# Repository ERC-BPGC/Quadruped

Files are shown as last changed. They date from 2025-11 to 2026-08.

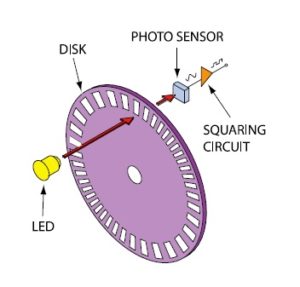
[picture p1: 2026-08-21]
docs/mechanical/assets/encoders/optical.jpg

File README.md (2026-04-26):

# ERC Quadruped

Official repository for the ERC-BPGC quadruped robotics project.

This repo is being organized into a long-term handoff and documentation hub for the robot: CAD, electronics, software, controls, simulation, assembly notes, experiments, and future work.

**Docs site:** https://erc-bpgc.github.io/Quadruped/

## Documentation

The project documentation is built with Docusaurus and hosted with GitHub Pages:

```text
https://erc-bpgc.github.io/Quadruped/
```

Local docs workflow:

```bash
nvm use
npm install
npm run start
```

Modern Docusaurus requires Node.js 20 or newer.

## Repository areas

- `docs/` - documentation pages
- `src/` - Docusaurus homepage and styling
- `static/` - images and static website assets
- `Genesis/` - simulation/source material currently present in the repo

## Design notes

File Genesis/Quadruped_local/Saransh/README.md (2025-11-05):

# Quadruped Control System

A comprehensive control system for a quadruped robot with ODrive motor controllers, featuring a GUI interface, live plotting, parameter tuning, and 3D visualization.

## Features

- **Configuration File System**: Easy-to-modify YAML configuration for all ODrive and system parameters
- **3D Visualization**: Interactive skeletal model with joint angle and foot position controls
- **Live Plotting**: Real-time plotting of motor currents, positions, velocities, and other parameters
- **Parameter Tuning**: Live modification of PID constants, current limits, and other ODrive parameters
- **Simulation Mode**: Test all functionality without hardware connection
- **Calibration System**: Simultaneous or sequential motor calibration
- **Emergency Controls**: Emergency stop and safety features

## File Structure

```
Quadruped/Saransh/
├── config.yaml                 # Main configuration file
├── quadruped_gui.py            # Main GUI application
├── quadruped_enhanced.py       # Enhanced quadruped control with config support
├── plotting_utils.py           # Plotting and data collection utilities
├── Quadruped_final_legs.py     # Original quadruped control (backward compatibility)
├── Quadruped_leg_test_algo.py  # Inverse kinematics algorithms
├── requirements.txt            # Python package requirements
└── README.md                   # This file
```

## Installation

1. **Install Python dependencies:**
   ```bash
   pip install -r requirements.txt
   ```

2. **Install ODrive (if using real hardware):**
   ```bash
   pip install odrive
   ```
   Follow the [ODrive setup guide](https://docs.odriverobotics.com/) for hardware setup.

3. **Verify installation:**
   ```bash
   python quadruped_gui.py
   ```

## Configuration

### Main Configuration File (config.yaml)

The `config.yaml` file contains all system parameters:

- **System Settings**: Simulation mode, calibration preferences
- **ODrive Mapping**: Serial number to leg assignment
- **Motor Parameters**: PID gains, current limits, encoder settings
- **Leg Geometry**: Link lengths and physical parameters
- **GUI Settings**: Window size, update rates, visualization options

### Key Configuration Sections

#### Motor Configuration
```yaml
motor_config:
  hip:
    pos_gain: 50.0
    vel_gain: 0.05
    current_lim: 20.0
    # ... other parameters
  knee:
    pos_gain: 20.0
    vel_gain: 0.02
    current_lim: 60.0
    # ... other parameters
```

#### ODrive Serial Mapping
```yaml
odrive_mapping:
  "3670314C3333": "front_left"
  "366B315F3333": "front_right"
  "367031553333": "back_left"
  "3669315C3333": "back_right"
```

## Usage

### GUI Application

1. **Start the GUI:**
   ```bash
   python quadruped_gui.py
   ```

2. **Simulation Mode:**
   - Set `simulation_mode: true` in config.yaml
   - Or toggle via the Connection menu
   - Test all features without hardware

3. **Hardware Mode:**
   - Set `simulation_mode: false` in config.yaml
   - Connect ODrives via "Connection" → "Connect to ODrives"

### GUI Tabs

#### 1. Visualization & Pose Control
- **3D Skeleton**: Interactive 3D model of the quadruped
- **Joint Controls**: Sliders for hip and knee angles
- **Foot Position**: X/Y position controls with inverse kinematics
- **Send to Dog**: Apply current pose to physical robot
- **Emergency Stop**: Immediate motor shutdown

#### 2. Motor Control
- Direct motor control interfaces
- Individual leg selection
- Position and velocity commands

#### 3. Live Plotting
- **Real-time Data**: Plot motor currents, positions, velocities
- **Parameter Selection**: Dropdown to choose what to plot
- **Multi-motor Display**: All 8 motors plotted simultaneously
- **Data Export**: Save plot data for analysis

#### 4. Parameter Tuning
- **Live PID Tuning**: Adjust gains in real-time
- **Current Limits**: Modify motor current limits
- **Velocity Limits**: Set speed constraints
- **Presets**: Save and load parameter configurations

#### 5. Calibration & Setup
- **Motor Calibration**: Simultaneous or sequential calibration
- **Home Position**: Set reference positions
- **Motor Testing**: Verify motor functionality

### Command Line Interface

1. **Original Interface:**
   ```bash
   python Quadruped_final_legs.py
   ```

2. **Enhanced Interface with Config:**
   ```bash
   python quadruped_enhanced.py
   ```

## Hardware Setup

### ODrive Configuration

1. **Serial Numbers**: Update `odrive_mapping` in config.yaml with your ODrive serial numbers
2. **Motor Parameters**: Adjust motor configurations for your specific motors
3. **Encoder Settings**: Configure for your encoder types (incremental for hips, hall for knees)

### Physical Connections

- **Front Left**: ODrive 1 (axis0: hip, axis1: knee)
- **Front Right**: ODrive 2 (axis0: hip, axis1: knee)
- **Back Left**: ODrive 3 (axis0: hip, axis1: knee)
- **Back Right**: ODrive 4 (axis0: hip, axis1: knee)

## Safety Features

### Emergency Stop
- **GUI Button**: Red emergency stop button in visualization tab
- **Keyboard**: Ctrl+C to interrupt operations
- **Automatic**: Safety limits in configuration

### Parameter Limits
```yaml
safety:
  max_current: 80.0
  max_velocity: 25.0
  max_position_error: 5.0
  emergency_stop_enabled: true
```

## Troubleshooting

### Common Issues

1. **ODrive Connection Failed**
   - Check USB connections
   - Verify serial numbers in config.yaml
   - Use `odrivetool` to test individual connections

2. **Calibration Errors**
   - Ensure motors can rotate freely
   - Check encoder wiring
   - Verify motor parameters

3. **GUI Not Starting**
   - Install missing dependencies: `pip install -r requirements.txt`
   - Check Python version (3.7+ required)

4. **Plotting Issues**
   - Reduce update rate in config.yaml
   - Check simulation_mode setting
   - Verify data collection parameters

### Debug Mode

Enable verbose output by modifying the configuration:
```yaml
system:
  debug_mode: true
  log_level: "DEBUG"
```

## Development

### Adding New Features

1. **New Parameters**: Add to `motor_config` in config.yaml
2. **GUI Widgets**: Extend the respective tab classes
3. **Plotting**: Add new parameters to `plotting_utils.py`

### Testing

1. **Simulation Mode**: Test without hardware
2. **Unit Tests**: Run individual components
3. **Hardware Testing**: Use with actual ODrives

## Support

- **Documentation**: See inline code comments
- **Configuration**: All parameters documented in config.yaml
- **Issues**: Check troubleshooting section above

## Version History

- **v1.0**: Initial GUI implementation with all major features
- **v0.9**: Enhanced quadruped control with config file support
- **v0.8**: Original command-line interface

## License

This project is part of the ERC Quadruped development effort.

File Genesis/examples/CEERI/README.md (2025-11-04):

# Indoor Drone Exploration with LiDAR

This directory contains a custom implementation of an autonomous indoor drone exploration system using reinforcement learning (PPO) with LiDAR-based navigation.

## 📋 Overview

This project implements a drone navigation system for indoor maze exploration based on the research paper:
**"Exploring Unknown Indoors with Drone using Multi-Critic DDPG Architecture"** (Kishore et al.)

The implementation uses:
- **2D LiDAR sensor** for obstacle detection (180° horizontal coverage)
- **Velocity-based control** (x_vel, y_vel, yaw_rate commands)
- **Hybrid reward structure** from the paper (variable pitch, obstacle avoidance, center alignment)
- **PPO algorithm** for training (single-critic, extensible to multi-critic later)
- **MJCF maze environment** with corridors, turns, and obstacles

## 🚀 Quick Start

### 0. Installation

Install required dependencies:

```bash
pip install --upgrade pip
pip install tensorboard rsl-rl-lib==2.2.4 pynput
```

### 1. Test Environment with Teleoperation

Before training, test the environment and visualize LiDAR sensor:

```bash
python exploration_teleop.py
```

**Keyboard Controls:**
- `↑/↓` : Forward/Backward
- `←/→` : Left/Right (lateral movement)
- `A/D` : Rotate Left/Right (yaw)
- `Space` : Stop (zero velocity)
- `R` : Reset drone
- `ESC` : Quit

The LiDAR rays will be visualized:
- **Green rays**: No obstacle detected
- **Red rays**: Obstacle hit

### 2. Train the Policy

Train the exploration policy using PPO:

```bash
# Basic training (4096 parallel environments)
python exploration_train.py -e drone-exploration -B 4096 --max_iterations 5001

# Training with visualization (slower but useful for debugging)
python exploration_train.py -e drone-exploration -B 4096 --max_iterations 5001 -v

# Quick test with fewer environments
python exploration_train.py -e test-exploration -B 256 --max_iterations 501
```

Monitor training progress with TensorBoard:
```bash
tensorboard --logdir logs/
```

### 3. Evaluate the Trained Policy

Evaluate the trained policy:

```bash
# Basic evaluation
python exploration_eval.py -e drone-exploration --ckpt 5000

# Evaluation with video recording
python exploration_eval.py -e drone-exploration --ckpt 5000 --record

# Evaluate multiple episodes
python exploration_eval.py -e drone-exploration --ckpt 5000 --num_episodes 20
```

## 📁 File Structure

```
CEERI/
├── exploration_env.py          # Main environment with LiDAR sensor
├── exploration_train.py        # Training script (PPO)
├── exploration_eval.py         # Evaluation script
├── exploration_teleop.py       # Manual control for testing
├── README.md                   # This file
└── logs/                       # Training logs and checkpoints
    └── drone-exploration/
        ├── model_*.pt          # Saved model checkpoints
        ├── cfgs.pkl            # Configuration file
        └── events.*            # TensorBoard logs
```

## 🎯 Environment Details

### Observation Space (15D)
- **LiDAR readings (3D)**: [F, R, L]
  - F: Minimum distance forward ([-10°, +10°])
  - R: Minimum distance right ([+10°, +90°])
  - L: Minimum distance left ([-90°, -10°])
- **Linear velocity (3D)**: [vx, vy, vz] in drone frame
- **Euler angles (3D)**: [roll, pitch, yaw]
- **Angular velocity (3D)**: [wx, wy, wz] in drone frame
- **Last actions (3D)**: Previous [x_vel, y_vel, yaw_rate] commands

### Action Space (3D)
- **x_vel**: Forward/backward velocity [-1.5, 1.5] m/s
- **y_vel**: Left/right velocity [-1.5, 1.5] m/s
- **yaw_rate**: Rotation rate [-π/2, π/2] rad/s

Actions are converted to rotor RPMs using a simple proportional controller.

### Reward Structure

Based on the research paper with 4 components:

1. **Variable Pitch** (forward movement encouragement)
   - Rewards faster movement when path is clear
   - Penalizes getting too close to obstacles

2. **Obstacle Avoidance** (repulsive potential)
   - Uses artificial potential hills around obstacles
   - Rewards decreasing repulsion equilibrium

3. **Center Alignment** (attractive potential)
   - Keeps drone centered in corridors
   - Minimizes difference between left/right distances

4. **Exploration** (placeholder)
   - Currently set to zero
   - Reserved for entropy-based exploration reward

Additional rewards:
- Collision penalty
- Smoothness penalty (action jerkiness)
- Angular velocity penalty

### Environment Configuration

Key parameters (see `exploration_env.py` and `exploration_train.py`):

```python
env_cfg = {
    "num_actions": 3,
    "episode_length_s": 60.0,
    "collision_threshold": 0.3,  # meters
    "lidar_n_rays": 128,
    "lidar_max_range": 6.0,  # meters
    "max_x_vel": 1.5,  # m/s
    "max_y_vel": 1.5,  # m/s
    "max_yaw_rate": 1.57,  # rad/s
}
```

## 🏗️ Maze Environment

The maze is defined in `/home/ritwik/NUS/Genesis/meshes/maze_simple.xml` (MJCF format).

Current maze features:
- 10m × 10m arena
- Corridors with varying widths
- Internal walls creating T-junctions
- Cylindrical obstacles/pillars

You can modify the maze by editing the XML file to add:
- More complex corridors
- Different obstacle shapes
- Dead ends and loops
- Multiple floors (for future 3D navigation)

## 🔧 Technical Details

### LiDAR Sensor
- **Type**: 2D (single horizontal plane)
- **FOV**: 180° horizontal ([-90°, +90°])
- **Resolution**: 128 rays (configurable)
- **Range**: 0.1m - 6.0m
- **Update rate**: 100 Hz (same as simulation)

### Velocity Controller
Simple proportional controller converts velocity commands to RPM:
- `kp_vel = 3000.0` for translational velocities
- `kp_yaw = 5000.0` for yaw rate
- Hover RPM: 14468
- RPM range: [5000, 25000]

### Drone Model
- Crazyflie 2.X (`urdf/drones/cf2x.urdf`)
- Quadcopter X-configuration
- Mass: ~0.027 kg
- 4 rotors with differential control

## 📊 Training Tips

1. **Start with fewer environments** (256-512) to verify setup
2. **Monitor TensorBoard** for reward trends and policy metrics
3. **Adjust reward scales** if one component dominates
4. **Use visualization** (`-v` flag) sparingly during training (slows down)
5. **Save checkpoints** regularly (default: every 100 iterations)

Typical training time:
- 256 envs: ~5-10 minutes per 100 iterations (CPU)
- 4096 envs: ~10-20 minutes per 100 iterations (GPU)

## 🎓 Future Extensions

- [ ] Add entropy-based exploration reward
- [ ] Implement multi-critic DDPG architecture
- [ ] Add precision playback buffer
- [ ] 3D LiDAR for vertical obstacle avoidance
- [ ] More complex maze environments
- [ ] Coverage tracking and visualization
- [ ] Real-world transfer (sim-to-real)

## 📚 References

**Paper**: "Exploring Unknown Indoors with Drone using Multi-Critic DDPG Architecture"  
**Authors**: Kaushal Kishore, Chimata Anudeep, Shahid Shaikh, Samarth Singh

Key concepts adapted:
- Hybrid reward structure (repulsive/attractive potentials)
- LiDAR-based state representation
- Multi-dimensional action space

## 🐛 Troubleshooting

**Issue**: Teleop script not responding to keyboard
- **Solution**: Install pynput: `pip install pynput`

**Issue**: MJCF maze not loading
- **Solution**: Check if `meshes/maze_simple.xml` exists. If not, the environment will create simple walls as fallback.

**Issue**: Training very slow
- **Solution**: Disable visualization (`-v` flag), reduce number of environments, or use GPU backend

**Issue**: Drone crashes immediately
- **Solution**: Check controller gains (`kp_vel`, `kp_yaw`), adjust collision threshold, or verify initial position is not inside a wall

## 📝 License

This project is part of the Genesis physics simulation framework research.

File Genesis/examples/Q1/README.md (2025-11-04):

# Q1 Quadruped Walking Task

This folder contains the training and evaluation code for a simple forward walking task for the Q1 custom quadruped robot.

## Robot Specifications

The Q1 quadruped has:
- **8 Degrees of Freedom (DOF)**: 2 per leg (thigh and calf joints only, no hip joint)
- **Joint Configuration**: 
  - Front Left (FL): thigh, calf
  - Front Right (FR): thigh, calf
  - Rear Left (RL): thigh, calf
  - Rear Right (RR): thigh, calf

This is different from robots like the Unitree Go2 which have 12 DOF (3 per leg: hip, thigh, and calf).

## Files

- `q1_env.py`: Environment class for Q1 robot with RL training interface
- `q1_train.py`: Training script using PPO algorithm
- `q1_eval.py`: Evaluation script to visualize trained policy
- `q1_visualize.py`: Standalone script to visualize robot in default pose
- `q1_monitor.py`: Real-time training progress monitor
- `README.md`: This file
- `MODIFICATIONS.md`: Detailed documentation of changes from Go2 code

## MuJoCo XML Files

The robot model is located at: `genesis/assets/xml/q1/q1_mjx_full.xml`

## Configuration

### Environment Configuration
- **Actions**: 8 continuous actions (one per joint)
- **Observations**: 33-dimensional vector containing:
  - Base angular velocity (3)
  - Projected gravity (3)
  - Velocity commands (3)
  - Joint positions relative to default (8)
  - Joint velocities (8)
  - Previous actions (8)

### Default Joint Angles
```python
"FL_thigh_joint": 0.5,
"FL_calf_joint": -0.3,
"FR_thigh_joint": 0.5,
"FR_calf_joint": -0.3,
"RL_thigh_joint": 0.5,
"RL_calf_joint": -0.3,
"RR_thigh_joint": 0.5,
"RR_calf_joint": -0.3,
```

### Reward Function
The reward function includes:
- **tracking_lin_vel** (1.5): Tracks desired forward velocity (0.5 m/s)
- **tracking_ang_vel** (0.5): Tracks desired angular velocity (0 rad/s)
- **lin_vel_z** (-2.0): Penalizes vertical movement
- **base_height** (-30.0): Maintains desired base height (0.35m)
- **action_rate** (-0.01): Encourages smooth actions
- **similar_to_default** (-0.2): Keeps joints near default pose

## Training

### Step 1: Visualize the Robot (Optional but Recommended)

First, verify that your robot model loads correctly:

```bash
cd /home/ritwik/NUS/Genesis
python examples/Q1/q1_visualize.py
```

This will open a viewer showing the Q1 robot in its default standing pose. Check that:
- The robot loads without errors
- All 8 joints are reported correctly
- The standing pose looks stable

### Step 2: Start Training

To train the Q1 robot for forward walking:

```bash
cd /home/ritwik/NUS/Genesis
python examples/Q1/q1_train.py
```

Optional arguments:
- `-e, --exp_name`: Experiment name (default: "q1-walking")
- `-B, --num_envs`: Number of parallel environments (default: 4096)
- `--max_iterations`: Maximum training iterations (default: 500)

Example:
```bash
python examples/Q1/q1_train.py -e q1-forward -B 2048 --max_iterations 1000
```

### Step 3: Monitor Training (Optional)

In a separate terminal, you can monitor training progress:

```bash
cd /home/ritwik/NUS/Genesis
python examples/Q1/q1_monitor.py -e q1-walking --interval 10
```

This will display updates about training checkpoints. You can also use TensorBoard:

```bash
tensorboard --logdir examples/Q1/logs/q1-walking
```

## Evaluation

To evaluate a trained policy:

```bash
python examples/Q1/q1_eval.py -e q1-walking --ckpt 500
```

Arguments:
- `-e, --exp_name`: Experiment name to load
- `--ckpt`: Checkpoint number to load (default: 500)

## Training Tips

1. **Initial Training**: Start with a lower number of iterations (500) to check if the robot learns basic stability
2. **Adjust Default Pose**: If the robot struggles to stand, adjust the default joint angles in `q1_train.py`
3. **Tuning PD Gains**: The gains are set to kp=25.0, kd=0.5. If joints oscillate, reduce kp. If joints are too sluggish, increase kp.
4. **Base Height**: The base_init_pos z-coordinate is set to 0.45m. Adjust this based on your robot's actual standing height.
5. **Reward Tuning**: 
   - Increase `tracking_lin_vel` weight if robot doesn't move forward enough
   - Increase `base_height` penalty if robot crouches too much
   - Adjust `action_rate` if actions are too jerky or too conservative

## Troubleshooting

### Robot Falls Immediately
- Check if default joint angles result in a stable standing pose
- Increase `base_height` penalty
- Verify base_init_pos height is appropriate

### Robot Doesn't Move Forward
- Increase `tracking_lin_vel` reward weight
- Decrease `similar_to_default` penalty
- Check if action_scale is appropriate (currently 0.3)

### Joint Oscillations
- Reduce PD gains (kp, kd)
- Increase `action_rate` penalty
- Check if joint limits in XML are appropriate

### Robot Tips Over
- Increase termination thresholds for roll/pitch
- Add more penalty for angular velocities
- Adjust base_height_target

## Next Steps

After achieving stable forward walking, you can:
1. Add turning capability by adjusting `ang_vel_range` in command_cfg
2. Add lateral movement by adjusting `lin_vel_y_range`
3. Add terrain variations
4. Implement velocity tracking for variable speed commands
5. Add additional reward terms for energy efficiency or foot clearance

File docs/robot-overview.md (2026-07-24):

---
title: Robot Overview
---

# Robot Overview

This page should become the practical entry point for the current robot: what it is, what revision it represents, what works today, and what a new contributor should understand first.

## Fill this first

- Current robot revision and photos.
- High-level dimensions, mass, degrees of freedom, and actuator count.
- What the robot can currently do.
- What is incomplete, unreliable, or experimental.
- The fastest path for a new member to understand the platform.

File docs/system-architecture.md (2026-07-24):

---
title: System Architecture
---

# System Architecture

This page should explain how the robot fits together as one system: mechanical structure, power, compute, motor drivers, sensors, communication links, and software stack.

## Diagrams to add

- Full robot block diagram.
- Power and communication architecture.
- Control loop overview from command to motor torque.
- Data flow between sensors, controller, drivers, and logs.

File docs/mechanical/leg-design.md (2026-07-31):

---
title: Leg Design
---

# Leg Design

The leg design evolved through prototyping. Since this was the first time most of the team was working on a system this large, we explored multiple actuation mechanisms before settling on the current architecture.

The goal of this page is to preserve that design history: what we tried, why we chose it, what worked, and why the next version changed.

## Image Folder

Put leg design images here:

```text
docs/mechanical/assets/leg-design/
```

Suggested filenames:

- `v0-leg-cad.png`
- `v0-ballscrew-knee.png`
- `v0-planetary-hip.png`
- `v1-leg-cad.png`
- `v1-cycloidal-tilt.png`
- `v1-pushrod-knee.png`

## Design Evolution

The first major decision was not just which motor to use, but how to transmit motor torque to each joint. Quadruped legs can use belts, gearboxes, ballscrews, linkages, direct drive, or combinations of these. Each option has tradeoffs in manufacturability, backlash, packaging, efficiency, mass, and repairability.

For our first robot, we prioritized mechanisms that we could actually manufacture, assemble, and iterate on with the tools and vendors available to us.

## V0: 2DOF Leg Prototype

The first prototype leg, V0, was a 2DOF leg with:

- hip actuation,
- knee actuation,
- no tilt/abduction-adduction axis.

This let us focus on the sagittal-plane leg mechanics before attempting a full 3DOF quadruped leg.

### Knee: Ballscrew Mechanism

The knee mechanism was the first major subsystem we tackled. After looking through quadruped actuator examples and available parts, we chose a ballscrew-based knee mechanism inspired by Spot-style linear actuator legs.

We chose this because:

- the mechanism was relatively easy to understand and manufacture,
- it avoided designing a compact custom gearbox for the knee,
- it avoided belt tensioning,
- ballscrews and linear motion parts were easier to source,
- the layout gave a clean way to actuate the calf link through push rods.

The actuation path was:

```text
motor rotation -> ballscrew linear motion -> 6 mm SS push rods -> calf link rotation
```

The knee used a Flipsky 5065 skateboard BLDC motor. It was chosen because the rough speed/torque estimate looked feasible, the long thin form factor fit the design well, and the motor had a built-in encoder.

TODO: Add the ballscrew-to-calf speed/torque ratio calculation here.

TODO: Add V0 knee CAD image or interactive CAD view here.

### Hip: Planetary Gearbox

For the hip/thigh link actuator, V0 used an Eaglepower 8308 pancake BLDC motor with a two-stage planetary gearbox. The total reduction was approximately 10:1.

This architecture was chosen because a pancake BLDC plus gearbox is a common setup for legged robot joints, and a planetary gearbox was one of the easiest reductions for us to start designing and manufacturing with 3D printing.

We used a two-stage design because a single-stage planetary with the required reduction would have made the 3D printed planet gears very small. That would have made them more likely to fracture under load.

TODO: Add V0 hip gearbox CAD image here.

TODO: Add gear ratio breakdown and expected output torque here.

## V1: Current 3DOF Leg

For the next version, V1, we moved to a full 3DOF leg while reusing whatever we could from V0.

The current leg has:

- tilt/abduction-adduction actuation,
- hip actuation,
- knee actuation.

### Tilt: Dual-Disc Cycloidal Actuator

The new tilt axis needed a compact actuator with enough torque for a full 3DOF leg. The old two-stage planetary gearbox was bulky and mechanically weak, so we wanted to move toward metal manufacturing.

The original idea was to make a single-stage metal planetary gearbox. However, we could not find suitable vendors for custom gear manufacturing at the time. We then moved to a cycloidal drive because its main profiles could be laser or plasma cut from metal sheet.

The V1 tilt actuator uses a dual-disc cycloidal drive. The dual-disc layout helps balance the drive compared to a single cycloidal disc.

Key design constraints:

- parts should be manufacturable from metal sheet,
- maximum practical sheet thickness was about 5 mm,
- the mechanism had to fit within the leg packaging,
- tolerances mattered a lot.

Cycloidal drives are sensitive to manufacturing tolerances, but after a few iterations we got the mechanism working.

TODO: Add cycloidal actuator CAD image and iteration notes here.

TODO: Add reduction ratio, eccentricity, pin count, and tolerance notes here.

### Hip: Reused Planetary Actuator

The V1 hip actuator reused the V0 hip setup:

```text
Eaglepower 8308 pancake BLDC -> two-stage planetary gearbox -> hip/thigh link
```

This was not necessarily the ideal final actuator, but reusing it helped us move toward a full 3DOF leg faster.

TODO: Add notes on observed weakness, backlash, or failures in the 3D printed planetary gearbox.

### Knee: Push/Pull Rod Mechanism

For V1, we initially tested the old ballscrew knee mechanism. It worked as a prototype, but it had two major drawbacks:

- it was heavy,
- it limited the final leg speed.

We then switched to a Go2-like push/pull rod mechanism. In the current version, the knee uses:

```text
Eaglepower 8308 pancake BLDC -> small pinion gear set -> push/pull rod -> calf link
```

This removed the heavy ballscrew and gave us a faster, more compact knee actuation path.

TODO: Add pinion ratio, linkage geometry, and knee torque/speed calculation here.

TODO: Add current V1 knee mechanism CAD image here.

## Current V1 Actuator Layout

| Joint | Mechanism | Motor | Notes |
| --- | --- | --- | --- |
| Tilt | Dual-disc cycloidal drive | Eaglepower 8308 BLDC | Metal sheet-manufacturable actuator for the new 3DOF leg. |
| Hip | Two-stage planetary gearbox | Eaglepower 8308 BLDC | Reused from V0; compact enough, but mechanically limited. |
| Knee | Pinion gear set + push/pull rod | Eaglepower 8308 BLDC | Replaced the heavier ballscrew mechanism. |

## Details To Add

- V0 and V1 CAD screenshots.
- Mechanism photos.
- Ballscrew speed/torque conversion calculation.
- Planetary gearbox ratio breakdown.
- Cycloidal reduction and tolerance notes.
- Push/pull rod linkage ratio and speed/torque estimate.
- Failure modes from testing.
- What we would redesign in the next revision.

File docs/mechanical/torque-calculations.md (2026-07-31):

---
title: Torque Calculations
---

# Torque Calculations

This page documents the quasi-static torque calculation used for our robot. It contains the model assumptions, free-body diagrams, equations, and MATLAB script used to sweep body height and estimate hip/knee torque.

For the general background behind choosing static, quasi-static, or dynamic methods, see [Joint Torque Sizing Theory](../theory/mechanical/joint-torque-sizing-theory.md).

## Model

We use a planar sagittal-plane model with two equal leg links. The thigh and calf have length `l`, and each link makes angle `theta` with the horizontal in the symmetric pose.

<figure className="figure--small">
  Overview of the simplified two-link leg model used for quasi-static torque sizing.
  <figcaption>Overview of the simplified two-link leg model. The stance foot provides a vertical normal reaction and a horizontal friction reaction; gravity acts on the body and link centers of mass.</figcaption>
</figure>

The height relation for this symmetric two-link geometry is:

$$
h = 2l\sin\theta
\qquad\Longrightarrow\qquad
\theta = \arcsin\left(\frac{h}{2l}\right)
$$

## Assumptions

- The robot is analyzed in the sagittal plane.
- Thigh and calf links have equal length `l`.
- The stance pose is symmetric, so both links use the same angle `theta`.
- Motion is quasi-static, so acceleration and impact forces are ignored.
- Loads are shared equally across `n` stance legs.
- The base mass is treated separately from the leg link masses.
- Foot friction is included in the FBD. For the symmetric stance case, the full robot has no external horizontal load, so the symmetric solution gives `F_friction = 0` for each stance foot.
- Transmission losses, bearing friction, motor heating, and gearbox efficiency are handled later using safety factors and motor datasheets.

## Parameters

| Symbol | Meaning |
| --- | --- |
| `m_base` | torso/base mass |
| `m_1` | thigh link mass |
| `m_2` | calf link mass |
| `m_leg` | mass of one leg, `m_1 + m_2` |
| `m_total` | total robot mass, `m_base + 4m_1 + 4m_2` |
| `n` | number of stance feet on the ground |
| `l` | thigh/calf link length |
| `g` | gravitational acceleration |
| `N` | vertical ground reaction at one stance foot |
| `N_1` | vertical load transmitted from torso/base into one stance leg |
| `N_3` | vertical knee reaction used in the thigh FBD |
| `N_4` | horizontal knee reaction used in the thigh FBD |

## Force Balance

For `n` stance legs, the vertical loads used in the FBD are:

$$
N_1 =
\frac{m_{\text{base}}g + m_{\text{leg}}(4-n)g}{n}
$$

$$
N_3 = N_1 + m_1g
$$

$$
N =
\frac{m_{\text{total}}g}{n}
$$

The foot friction term deserves a bit of care. If we isolate one leg, the horizontal equilibrium equations give:

$$
N_4 = F_{\text{friction}},
\qquad
N_2 = N_4
$$

So the single-leg equations tell us that the horizontal contact force propagates through the calf, knee, and hip reactions. They do not determine its magnitude by themselves.

To determine `F_friction`, we need the whole-robot horizontal equilibrium condition. In symmetric standing, there is no external horizontal load and every stance leg is assumed to carry the same horizontal reaction. Therefore:

$$
\sum F_x = 0
\qquad\Longrightarrow\qquad
nF_{\text{friction}} = 0
\qquad\Longrightarrow\qquad
F_{\text{friction}} = 0
$$

For the symmetric stance case:

$$
F_{\text{friction}} = 0,
\qquad
N_4 = F_{\text{friction}} = 0
$$

In a non-symmetric case, such as a body acceleration, slope, external push, or uneven contact distribution, `F_friction` should be solved from the full-body equilibrium/dynamics and checked against the friction limit:

$$
|F_{\text{friction}}| \leq \mu N
$$

## Thigh Link

<figure className="figure--small">
  Free-body diagram of the thigh link.
  <figcaption>Thigh link free-body diagram. Taking moments about the hip removes the hip reaction forces from the torque equation.</figcaption>
</figure>

Taking moments about the hip joint:

$$
\tau_1
+ m_1g\cos\theta\frac{l}{2}
+ N_4\sin\theta l
= N_3\cos\theta l
$$

So the hip torque is:

$$
\tau_1 =
N_3\cos\theta l
- m_1g\cos\theta\frac{l}{2}
- N_4\sin\theta l
$$

For the symmetric stance case, `N_4 = 0`, so this reduces to:

$$
\tau_1 =
N_3\cos\theta l
- m_1g\cos\theta\frac{l}{2}
$$

## Calf Link

<figure className="figure--small">
  Free-body diagram of the calf link.
  <figcaption>Calf link free-body diagram. The knee reactions are equal and opposite to the reactions shown on the thigh FBD.</figcaption>
</figure>

Taking moments about the knee joint:

$$
\tau_2
+ m_2g\cos\theta\frac{l}{2}
+ F_{\text{friction}}\sin\theta l
= N\cos\theta l
$$

So the knee/calf torque is:

$$
\tau_2 =
N\cos\theta l
- m_2g\cos\theta\frac{l}{2}
- F_{\text{friction}}\sin\theta l
$$

For the symmetric stance case:

$$
\tau_2 =
N\cos\theta l
- m_2g\cos\theta\frac{l}{2}
$$

## MATLAB Script

This script sweeps body height, computes `theta`, evaluates the hip and knee torque equations, and prints the maximum torque for different stance-leg counts.

```matlab
% Quadruped quasi-static joint torque sizing.
%
% Assumptions:
%   - 2D sagittal-plane analysis
%   - equal thigh/calf lengths
%   - symmetric stance geometry
%   - quasi-static motion
%   - equal load sharing across n stance legs
%   - no horizontal external load in the symmetric stance case

clear; clc; close all;

% -------------------------------------------------------------------------
% Robot parameters
% -------------------------------------------------------------------------
m_base = 17.5;   % [kg] base/torso mass
m1 = 1.55;       % [kg] thigh link mass
m2 = 0.25;       % [kg] calf link mass
l = 0.30;        % [m] thigh/calf link length
g = 9.81;        % [m/s^2] gravity

stance_cases = [4, 3, 2];

% -------------------------------------------------------------------------
% Derived parameters
% -------------------------------------------------------------------------
m_leg = m1 + m2;
m_total = m_base + 4*m1 + 4*m2;

% Avoid h = 0 and h = 2l singular/end-point cases.
h_min = 0.05;
h_max = 2*l*0.99;
h = linspace(h_min, h_max, 500);
theta = asin(h ./ (2*l));
h_cm = h * 100;

fprintf("\n========================================\n");
fprintf("  QUASI-STATIC TORQUE ANALYSIS SUMMARY\n");
fprintf("========================================\n");
fprintf("Base mass:             %.2f kg\n", m_base);
fprintf("Total mass:            %.2f kg\n", m_total);
fprintf("Thigh mass m1:         %.2f kg\n", m1);
fprintf("Calf mass m2:          %.2f kg\n", m2);
fprintf("Link length l:         %.3f m\n", l);
fprintf("Height range:          %.1f cm to %.1f cm\n", h_cm(1), h_cm(end));
fprintf("----------------------------------------\n");

figure("Name", "Quasi-static joint torque sizing", ...
       "Position", [100 100 1000 520]);

tiledlayout(1, 2);
nexttile;
hold on;
grid on;
xlabel("Body height h [cm]");
ylabel("Joint torque [Nm]");
title("Hip and knee torque vs height");

results = struct([]);

for i = 1:numel(stance_cases)
    n = stance_cases(i);

    % Vertical load transmitted from the torso/base into one stance leg.
    N1 = (m_base*g + m_leg*(4 - n)*g) / n;

    % Vertical ground reaction at one stance foot.
    N = m_total*g / n;

    % Vertical reaction at the knee from thigh-link force balance.
    N3 = N1 + m1*g;

    % Symmetric stance: no external horizontal load.
    F_friction = zeros(size(h));
    N4 = F_friction;

    tau_hip = N3 .* cos(theta) .* l ...
        - m1*g .* cos(theta) .* (l/2) ...
        - N4 .* sin(theta) .* l;

    tau_knee = N .* cos(theta) .* l ...
        - m2*g .* cos(theta) .* (l/2) ...
        - F_friction .* sin(theta) .* l;

    [max_hip, idx_hip] = max(tau_hip);
    [max_knee, idx_knee] = max(tau_knee);

    results(i).n = n;
    results(i).N1 = N1;
    results(i).N = N;
    results(i).N3 = N3;
    results(i).max_hip = max_hip;
    results(i).max_knee = max_knee;
    results(i).hip_height_cm = h_cm(idx_hip);
    results(i).knee_height_cm = h_cm(idx_knee);

    plot(h_cm, tau_hip, "LineWidth", 2, ...
        "DisplayName", sprintf("hip, n = %d", n));
    plot(h_cm, tau_knee, "--", "LineWidth", 2, ...
        "DisplayName", sprintf("knee, n = %d", n));

    fprintf("n = %d stance legs\n", n);
    fprintf("  N1 hip vertical load:   %.2f N\n", N1);
    fprintf("  N foot normal:          %.2f N\n", N);
    fprintf("  N3 knee vertical load:  %.2f N\n", N3);
    fprintf("  Max hip torque:         %.2f Nm at h = %.1f cm\n", ...
        max_hip, h_cm(idx_hip));
    fprintf("  Max knee torque:        %.2f Nm at h = %.1f cm\n", ...
        max_knee, h_cm(idx_knee));
    fprintf("----------------------------------------\n");
end

legend("Location", "best");

nexttile;
plot(h_cm, rad2deg(theta), "k", "LineWidth", 2);
grid on;
xlabel("Body height h [cm]");
ylabel("Link angle theta [deg]");
title("Geometry relation");

fprintf("Friction check for symmetric stance: F_friction = 0 N\n");
fprintf("For non-symmetric cases, solve F_friction and check |F| <= mu*N.\n");
fprintf("========================================\n\n");
```

## Sizing Cases

| Case | Description | Why it matters |
| --- | --- | --- |
| `n = 4` | All four feet on the ground. | Baseline standing load. |
| `n = 3` | One leg lifted. | Slow walking or transition case. |
| `n = 2` | Two stance legs. | Conservative case for trot-like support. |

After MATLAB gives the maximum torque values, we apply a safety factor to account for modeling simplifications, impact loads, acceleration, and transmission losses.

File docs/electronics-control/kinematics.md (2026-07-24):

---
title: Kinematics
---

# Kinematics

This page should document the kinematics used by our robot: coordinate frames, joint signs, forward kinematics, inverse kinematics, and the exact conventions used in code.

## Fill this first

- Body and leg coordinate frames.
- Joint angle signs and zero positions.
- Link lengths and offsets.
- Forward/inverse kinematics equations or code references.
- Test poses for sanity-checking signs.

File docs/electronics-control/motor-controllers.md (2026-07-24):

---
title: Motor Controllers
---

# Motor Controllers

This page should document the motor drivers/controllers used on the robot and how they are configured for the actuator modules.

## Fill this first

- Driver model and firmware.
- Motor phase wiring and encoder connection.
- Current, voltage, velocity, and position limits.
- CAN/UART/USB configuration.
- Calibration and recovery notes.

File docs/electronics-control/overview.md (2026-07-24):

---
title: Electronics and Control Overview
---

# Electronics and Control Overview

This page should explain the electrical and control stack at a high level: power, motor drivers, sensors, communication, control loops, and safety boundaries.

## Fill this first

- Main electrical components and responsibilities.
- Control loop frequencies and where each loop runs.
- Communication buses.
- Safety limits and emergency-stop behavior.
- Links to wiring, setup, and test pages.

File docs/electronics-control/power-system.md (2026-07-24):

---
title: Power System
---

# Power System

This page should document the robot battery, power distribution, voltage rails, current limits, fusing/protection, and power-up/power-down sequence.

## Fill this first

- Battery chemistry, voltage, capacity, and connector.
- Power distribution board or wiring path.
- Regulator rails and current ratings.
- Fuse/current-limit choices.
- Known risks and safe handling notes.

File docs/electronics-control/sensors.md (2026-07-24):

---
title: Sensors
---

# Sensors

This page should document the sensors used on the robot, what each one measures, and how the data enters the control stack.

## Fill this first

- Joint encoders.
- IMU.
- Any foot/contact sensing.
- Sensor rates and communication protocols.
- Calibration steps and known failure modes.

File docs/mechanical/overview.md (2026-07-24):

---
title: Mechanical Overview
---

# Mechanical Overview

This page should become the mechanical source of truth for our robot: dimensions, CAD files, link geometry, joint layout, fasteners, materials, manufacturing notes, and assembly order.

## Fill this first

- Final CAD location and export formats.
- Exploded assembly screenshots.
- Leg naming convention: front-left, front-right, rear-left, rear-right.
- Joint order and sign conventions.
- Link lengths and offsets used by control code.
- Known weak points, alignment issues, and manufacturing tolerances.

## Useful page structure

1. Architecture and design goals.
2. CAD file map.
3. Bill of materials.
4. Assembly sequence.
5. Known issues and revision ideas.

## Current pages

- [Torque Calculations](./torque-calculations.md): robot-specific torque numbers, MATLAB output, assumptions, and safety factor.
- [Leg Design](./leg-design.md): actual leg architecture, geometry, joints, materials, and known mechanical issues.
- [CAD and Fabrication](./cad-and-fabrication.md): CAD file map, exports, materials, and manufacturing notes.

For general background, see the [Mechanical theory pages](../theory/mechanical/actuation-survey.md).

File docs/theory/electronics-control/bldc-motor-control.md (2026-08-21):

---
title: BLDC Motor Control
---

# BLDC Motor Control

BLDC motors are brushless DC motors: permanent magnets sit on the rotor, and coils on the stator are energized electronically to create a rotating magnetic field. They are common in robots because they have high power density, good efficiency, fast torque response, and no brush wear.

In a BLDC motor, the controller switches current through different stator phases so the magnetic field keeps pulling the rotor forward. To do this well, the controller needs to know or estimate rotor position, then energize the phases with the correct timing. Better timing gives smoother torque, higher efficiency, and better low-level control.

<div className="figure-grid figure-grid--two figure-grid--compact">
  <figure>
    Animated BLDC motor phase switching
    <figcaption>BLDC phase switching creates a rotating magnetic field.</figcaption>
  </figure>
  <figure>
    Animated BLDC motor rotor following stator magnetic field
    <figcaption>The rotor follows the stator field as the controller commutates the phases.</figcaption>
  </figure>
</div>

## Video Resources

- [How does a brushless DC motor work?](https://www.youtube.com/watch?v=bCEiOnuODac)
- [BLDC motor control explanation](https://www.youtube.com/watch?v=IkRoEfy-PPQ)

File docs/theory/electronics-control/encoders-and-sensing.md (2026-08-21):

---
title: Encoders and Sensing
---

# Encoders and Sensing

Encoders measure position. In a quadruped, they are one of the most important sensors because the controller needs to know where each motor and joint actually is before it can control torque, velocity, position, or leg kinematics.

Bad encoder data can make a good actuator look terrible. A loose magnet, wrong offset, noisy cable, or reversed direction can cause jitter, heating, instability, or violent motion.

## Common Sensing Technologies

| Type | Basic idea | Notes |
| --- | --- | --- |
| Hall sensors | Detect rotor magnetic pole transitions. | Cheap and robust, but low resolution. Common inside BLDC motors for basic commutation. |
| Magnetic encoder | Uses a magnetic field sensor IC and a small magnet mounted on the rotating shaft. | Compact and common in hobby/robotics builds. Many chips provide 10-12 bit or higher angle readings. |
| Optical encoder | Uses light and slots/marks on a disk to measure rotation. | Can be high resolution, but needs cleaner mechanical alignment and protection from dust/oil. |

<div className="figure-grid figure-grid--three figure-grid--compact">
  <figure>
    Hall sensor based motor position sensing
    <figcaption>Hall sensors are simple and robust, but usually low resolution.</figcaption>
  </figure>
  <figure>
    Magnetic encoder with diametric magnet and sensor IC
    <figcaption>Magnetic encoders are compact and common in robot joints.</figcaption>
  </figure>
  <figure>
    Optical rotary encoder disk and sensor
    <figcaption>Optical encoders can be precise, but need clean alignment.</figcaption>
  </figure>
</div>

## Incremental vs Absolute

Incremental and absolute describe how the encoder reports position. They are separate from the physical sensing method: magnetic, optical, and other encoder technologies can be designed as either incremental or absolute sensors.

### Incremental Encoders

Incremental encoders report motion as pulses relative to a starting point. They are useful for measuring speed and relative movement, but after power-on the controller does not automatically know the absolute shaft angle.

To recover absolute position, incremental systems usually need:

- a homing routine,
- a limit switch,
- an index pulse,
- or a known startup pose.

### Absolute Encoders

Absolute encoders report the actual angle immediately after power-on. This is very useful for robot joints because the controller can know the leg pose before moving the robot.

Absolute encoders still need calibration. The sensor may know its own shaft angle, but the robot still needs a zero offset that maps that sensor angle to the mechanical joint convention.

## PPR, CPR, and Resolution

Encoder specs can be confusing because manufacturers use different terms.

| Term | Meaning |
| --- | --- |
| `PPR` | Pulses per revolution. Often used for incremental encoders. |
| `CPR` | Counts per revolution. With quadrature decoding, one pulse cycle can produce multiple counts. |
| Resolution | Smallest angle step the sensor can report. |
| Bit depth | For digital absolute encoders, `bits` determine how many discrete positions exist per revolution. |

For an absolute encoder:

```text
counts_per_revolution = 2^bits
```

Examples:

| Bit depth | Counts per revolution | Angle per count |
| --- | --- | --- |
| 10-bit | 1024 | about 0.35 deg |
| 12-bit | 4096 | about 0.088 deg |
| 14-bit | 16384 | about 0.022 deg |

For a quadrature incremental encoder, the effective count rate depends on how the signals are decoded. If an encoder is listed as `PPR`, the controller may count 1x, 2x, or 4x that value depending on whether it counts rising edges only, both edges, or all quadrature transitions.

## Motor Angle vs Joint Angle

An encoder can measure either:

- motor shaft angle,
- gearbox output angle,
- joint angle directly.

These are not always the same. If there is a gearbox, belt, linkage, or push rod between the motor and joint, motor angle must be converted to joint angle using the mechanism ratio and geometry.

Motor-side encoders are usually easier to package and useful for motor commutation. Joint-side encoders give better knowledge of the actual joint position, especially when there is backlash, belt stretch, compliance, or linkage nonlinearity.

## Common Failure Points

### Bad Mechanical Mounting

This is one of the most common mistakes in hobby and student robot builds.

For magnetic encoders:

- the magnet must be centered over the sensor,
- the air gap must be within the sensor's recommended range,
- the magnet must be mounted flat and coaxial with the rotating shaft,
- the magnet must not wobble, slip, or tilt during motion,
- the sensor PCB must be rigidly mounted,
- glue alone is risky if the magnet can shift under vibration.

For optical encoders:

- the disk must be concentric with the shaft,
- the sensor gap and alignment must be correct,
- the disk must not rub or wobble,
- dust, grease, and scratches can corrupt readings.

If the encoder is mechanically misaligned, the software may still receive numbers, but those numbers can be nonlinear, noisy, delayed, or completely wrong.

### Wrong Direction

If motor current produces positive torque but the encoder angle decreases, the control loop may run away instead of stabilizing. Always check encoder sign before enabling high current.

### Bad Zero Offset

Absolute encoders still need a joint zero convention. If the offset is wrong, the robot may think a safe pose is actually outside its limits, or inverse kinematics may command the wrong motion.

### Noise and Wiring Issues

Encoder signals can be corrupted by:

- long unshielded wires,
- routing sensor wires near motor phase wires,
- poor grounding,
- loose connectors,
- bad crimping,
- weak pull-ups,
- low supply voltage,
- communication bus errors.

### Insufficient Resolution

Low-resolution sensors can make control rough, especially for slow joint motion or velocity estimation. A motor may sound noisy or feel jerky simply because the controller cannot measure position smoothly enough.

### Backlash or Compliance

If the encoder is on the motor side, backlash or flex after the encoder will not be measured. The controller may think the motor is positioned correctly while the actual joint is slightly behind or oscillating.

## Practical Checks

- Rotate the joint by hand and plot encoder angle.
- Check that the angle changes smoothly without jumps.
- Verify direction/sign against the joint convention.
- Mark a physical zero position and confirm the reported offset.
- Wiggle cables and connectors while watching readings.
- Run motors at low current first.
- Recheck encoder mounting after impacts or transport.

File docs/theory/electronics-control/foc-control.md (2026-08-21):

---
title: FOC Control
---

# FOC Control

BLDC motors need electronic commutation: the controller must decide how to energize the stator phases so the rotor keeps producing useful torque. There are a few common ways to do this.

## Common Control Methods

| Method | Basic idea | Notes |
| --- | --- | --- |
| 6-step / trapezoidal commutation | Energize two phases at a time in six discrete steps as the rotor moves. | Simple, efficient enough for many applications, but torque ripple is higher and low-speed control is rougher. |
| Sinusoidal commutation | Drive the phases with smooth sinusoidal currents instead of discrete steps. | Smoother than 6-step, but still does not fully decouple torque and magnetic flux. |
| SVPWM | Space Vector PWM chooses inverter switching states to synthesize the desired voltage vector efficiently. | Often used inside modern motor controllers because it uses bus voltage well and produces smooth phase voltages. |
| FOC | Field-oriented control transforms phase currents into a rotating reference frame so torque-producing current can be controlled directly. | More complex, but gives smooth, accurate torque control across a wide speed range. |

Many hobby drone ESCs traditionally use sensorless trapezoidal/6-step-style commutation because drone motors mostly spin fast in one direction, where this works well. Some newer ESCs use more advanced sinusoidal or FOC-like methods, but the common mental model people know from drones is still: BLDC motor plus ESC, optimized for high-speed propeller control.

Legged robots need something different. A quadruped joint often moves slowly, reverses direction, gets hit by the ground, holds torque at near-zero speed, and needs predictable force output. This is where FOC becomes much more useful.

## Basic Idea Of FOC

FOC measures or estimates the rotor angle, then mathematically rotates the three phase currents into two useful current components:

- `d-axis current`: aligned with the rotor magnetic field,
- `q-axis current`: perpendicular to the rotor field and mainly responsible for torque.

For most permanent-magnet BLDC motors used in robot actuators, the controller tries to keep `d-axis current` near zero and control `q-axis current` to produce the desired torque. In simple terms:

```text
desired torque -> desired q-axis current -> phase currents -> motor torque
```

This makes the motor feel much more like a controllable torque source instead of just a spinning motor.

## Why FOC Is Ideal For Legged Robotics

FOC is more work than a basic ESC. It usually needs rotor position feedback or good sensorless estimation, current sensing, fast control loops, and careful tuning. The payoff is that it gives the kind of actuator behavior legged robots need:

- smooth torque at low speed,
- fast torque response,
- bidirectional control,
- better efficiency and lower torque ripple,
- current limiting for safety,
- torque/current control that can be wrapped inside velocity, position, impedance, or whole-body controllers.

This is why BLDC motors with FOC are commonly used to build robust, dynamic, "springy" robot actuators. Instead of commanding a stiff servo position and hoping the gearbox survives impacts, the controller can make the joint behave like a virtual spring-damper:

```text
joint torque = stiffness * position_error + damping * velocity_error
```

That kind of impedance behavior is extremely useful for legged robots because the feet constantly interact with the ground. Compared to steppers or hobby servos, a BLDC + FOC actuator can be more backdrivable, more impact tolerant, and better suited for dynamic force control.

## Video Resources

- [BLDC motor control methods and FOC explanation](https://www.youtube.com/watch?v=e0sQnVmE7DU)
- [Motor control playlist with MATLAB examples](https://www.youtube.com/watch?v=a5PWePUTR-0&list=PLl6mqZGq1o09k59iLGNs7AdLuJi9FoVcV&index=4)

For the MATLAB playlist, the goal for now is just to understand the control idea. There is no need to work through the MATLAB code yet.

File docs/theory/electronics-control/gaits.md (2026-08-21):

---
title: Gaits
---

# Gaits

A gait is the repeated footfall pattern a legged robot uses to move. It defines which legs are in stance, which legs are in swing, and how the body shifts while the feet move.

In quadrupeds, the gait affects stability, speed, efficiency, ground reaction forces, and how hard the controller has to work.

## Common Gaits

| Gait | Basic idea | Notes |
| --- | --- | --- |
| Walk | Legs move one at a time. | Slow, stable, and easy to reason about. |
| Crawl | Very slow walking with a large stability margin. | Useful for careful motion or rough terrain. |
| Trot | Diagonal leg pairs move together. | Common for quadruped robots because it balances speed and simplicity. |
| Pace | Same-side legs move together. | Can be fast, but body roll control becomes important. |
| Bound | Front legs and rear legs move as pairs. | Dynamic gait used for faster motion. |
| Gallop | Asymmetric high-speed gait. | More dynamic and harder to control. |

<figure className="figure--small">
  Animation comparing common quadruped gait patterns
  <figcaption>Common quadruped gait patterns and their leg timing.</figcaption>
</figure>

## Useful Terms

- **Stance phase:** the foot is on the ground and supporting/pushing the body.
- **Swing phase:** the foot is in the air moving to the next contact point.
- **Duty factor:** fraction of the gait cycle that a foot spends in stance.
- **Support polygon:** area formed by the stance feet; the robot is more statically stable when the center of mass projection stays inside it.

## Resource

- [Animator Notebook: Quadrupeds Gaits](https://www.animatornotebook.com/learn/quadrupeds-gaits)

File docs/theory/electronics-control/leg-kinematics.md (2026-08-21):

---
title: Leg Kinematics
---

# Leg Kinematics

For legged robots, kinematics is mostly about converting between joint angles and foot position.

- **Forward kinematics:** given joint angles, find where the foot is.
- **Inverse kinematics:** given a desired foot position, find the joint angles needed to place the foot there.

Inverse kinematics, or IK, is especially important because gait planners usually think in terms of foot trajectories: lift the foot, move it forward, place it down, shift the body, and repeat. The motor controller does not directly understand "put the foot here"; it needs joint angle targets.

```text
desired foot position -> inverse kinematics -> joint angle targets -> motor control
```

## Simple 2DOF Planar Leg

Start with a simple planar leg with two links:

- thigh length `l_1`,
- calf length `l_2`,
- hip angle `q_1`,
- knee angle `q_2`,
- desired foot point `(x, z)` relative to the hip.

The distance from hip to foot is:

$$
r = \sqrt{x^2 + z^2}
$$

Using the law of cosines, the knee angle can be found from:

$$
\cos q_2 =
\frac{x^2 + z^2 - l_1^2 - l_2^2}{2l_1l_2}
$$

So:

$$
q_2 =
\cos^{-1}\left(
\frac{x^2 + z^2 - l_1^2 - l_2^2}{2l_1l_2}
\right)
$$

The hip angle can be found by splitting it into two angles:

$$
q_1 =
\tan^{-1}\left(\frac{z}{x}\right)
-
\tan^{-1}\left(
\frac{l_2\sin q_2}{l_1 + l_2\cos q_2}
\right)
$$

In code, use `atan2` instead of plain `atan` so the quadrant is handled correctly:

```text
q_1 = atan2(z, x) - atan2(l_2 sin(q_2), l_1 + l_2 cos(q_2))
```

Depending on the leg convention, knee direction, and whether `z` is positive upward or downward, these equations may need sign changes. Always match the equations to the CAD, motor direction, and encoder zero convention used on the robot.

## Reachability

Not every foot position is physically reachable. For a two-link leg:

$$
|l_1 - l_2| \leq r \leq l_1 + l_2
$$

If the desired foot point is outside this range, the leg cannot reach it. Real robots also have joint limits, linkage interference, body collisions, cable limits, and torque limits, so the usable workspace is smaller than the ideal mathematical workspace.

## Extending To 3DOF Legs

A 3DOF quadruped leg usually adds a hip abduction/adduction, or tilt, joint. A common approach is:

1. Use the tilt joint to rotate the desired foot point into the sagittal plane of the leg.
2. Solve the remaining 2DOF hip/knee IK in that plane.
3. Convert the resulting joint angles into motor commands using the robot's sign conventions and offsets.

The core idea is the same: choose a desired foot position, solve geometry for joint angles, then send those angles to the lower-level controllers.

## Practical Notes

- Define coordinate frames before writing equations.
- Use `atan2`, not plain `atan`.
- Clamp the cosine argument to `[-1, 1]` before calling `acos` to avoid numerical errors.
- Check joint limits after solving IK.
- Test simple poses first: foot straight down, foot forward, foot backward.
- Plot or animate the leg to catch sign mistakes.
- Make sure encoder zero offsets match the IK convention.

## Resources

- [Inverse Kinematics: Go2 Robot's Leg](https://observablehq.com/@christophe-yamahata/inverse-kinematics-go2-robot), an interactive Go2 leg IK reference.
- [Inverse kinematics video explanation](https://www.youtube.com/watch?v=cqpYpj8EaDY&t=91s)

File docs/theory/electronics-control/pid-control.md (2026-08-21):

---
title: PID Control
---

# PID Control

PID control is one of the most common control ideas in robotics. It shows up anywhere we want a system to follow a target: motor velocity, joint position, joint torque/current, body attitude, leg height, or even higher-level balance behavior.

For legged robots, PID-style feedback is especially important at the low level. Even if the robot eventually uses advanced gait planning, model predictive control, reinforcement learning, or whole-body control, the actuators still need stable feedback loops that can track commands quickly and reject disturbances.

This page is only a resource hub for now. The best way to understand PID is to watch it, tune it, and see how the response changes.

## Video Resources

- [Understanding PID control - MATLAB Tech Talks playlist](https://www.youtube.com/watch?v=wkfEZmsQqiA&list=PLn8PRpmsu08pQBgjxYFXSsODEF3Jqmm-y)
- [PID control explanation](https://www.youtube.com/watch?v=qKy98Cbcltw)
- [PID controller basics](https://www.youtube.com/watch?v=JFTJ2SS4xyA)
- [PID tuning / control demo](https://www.youtube.com/watch?v=dMRDzicSvXk&t=799s)

## Interactive Demos

- [PID controller interactive demo](https://codepen.io/oscarsaharoy/full/LYbmVma)
- [PID drone control demo](https://pid-drone-control.vercel.app/)

## Where PID Shows Up On A Quadruped

- motor current/torque loops,
- motor velocity loops,
- joint position loops,
- leg endpoint tracking,
- body roll/pitch stabilization,
- balancing and disturbance rejection.

The main lesson: PID is simple, but not optional. A poorly tuned low-level loop can make even a good mechanical design look unstable.

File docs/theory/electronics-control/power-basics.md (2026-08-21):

---
title: Power Basics
---

# Power Basics

Robot power is not just about choosing a battery with the right voltage. A quadruped has motors that draw large changing currents, electronics that need clean regulated power, and safety risks that become very real when many actuators can move at once.

This page is a quick background reference for the power concepts that matter before working on the robot.

## Voltage, Current, and Power

Voltage is the electrical potential available to push current through a circuit. Current is the flow of charge. Power is the rate at which electrical energy is delivered:

$$
P = VI
$$

For a robot, this means:

- higher voltage can deliver the same power with lower current,
- high current causes heating in wires, connectors, batteries, and motor drivers,
- every wire, connector, switch, fuse, PCB trace, and driver must be rated for the expected current,
- motors can draw much more current during startup, hard acceleration, collision, or stall than they do during light motion.

## Batteries

Legged robots commonly use lithium battery packs because they have high power density. The important battery parameters are:

| Parameter | Why it matters |
| --- | --- |
| Nominal voltage | Sets the main bus voltage for motor drivers and regulators. |
| Capacity | Roughly determines runtime. |
| Discharge rating | Determines how much current the battery can safely supply. |
| Internal resistance | Causes voltage sag and heating under high current. |
| Connector rating | A weak connector can heat up or fail even if the battery itself is fine. |

Battery voltage is not constant. It changes with charge level, load current, and battery health. A motor controller must tolerate the full battery voltage range, not just the nominal value.

## Power Distribution

A quadruped usually has at least two power domains:

- **high-power motor bus:** battery voltage feeding motor drivers,
- **low-voltage electronics rails:** regulated power for compute, sensors, microcontrollers, and communication hardware.

Keep these ideas in mind:

- Motor current paths should be short, thick, and mechanically secure.
- Logic power should be regulated and protected from motor noise.
- Grounds must be planned carefully so high motor currents do not corrupt sensor or communication signals.
- Current return paths matter as much as positive supply paths.

## Protection and Safety

Useful safety elements include:

- **Fuses or resettable protection:** disconnect power during severe overcurrent faults.
- **Emergency stop:** provides a fast way to disable actuator power.
- **Reverse-polarity protection:** protects electronics if a connector is accidentally reversed.
- **Pre-charge or soft-start:** limits inrush current into large capacitors.
- **Current limits in motor controllers:** prevent motors and drivers from pulling destructive current.
- **Clear power-up sequence:** avoids enabling motors before sensors and controllers are ready.

Before applying power, always check polarity, continuity, expected resistance between supply rails, connector orientation, and whether anything conductive is loose inside the robot.

## Capacitors and Voltage Spikes

Motors and drivers create fast current changes. Wiring inductance resists sudden current changes, which can create voltage spikes on the power bus. Capacitors near motor drivers help absorb short spikes and supply quick bursts of current.

Common capacitor roles:

- **bulk capacitance:** supports the main bus during short current bursts,
- **decoupling capacitance:** filters high-frequency noise near electronics,
- **driver input capacitance:** stabilizes the motor controller supply.

Capacitors are useful, but they also create inrush current when the robot is first connected to a battery. Large capacitor banks may need pre-charge or soft-start circuitry.

## Safe Measurement Habits

- Start with a current-limited bench supply when testing new electronics.
- Use a multimeter to verify voltage before plugging in sensitive boards.
- Never assume connector polarity from color alone.
- Keep one hand away from the circuit when probing high-current systems.
- Secure the robot mechanically before enabling actuators.
- Disable motors before changing wiring.

## Video Resource

- [Electricity basics for robotics/electronics](https://www.youtube.com/watch?v=Iye4uVLmj8o)

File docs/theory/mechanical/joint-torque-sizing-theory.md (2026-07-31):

---
title: Joint Torque Sizing Theory
---

# Joint Torque Sizing Theory

Before choosing motors and gearboxes, we need a first estimate of how much torque each joint must hold. The exact numbers depend on the robot geometry and mass distribution, but the analysis method is general.

The goal is not to perfectly predict running, jumping, impact, or control transients. The goal is to understand which kind of calculation is appropriate at each stage of the design.

## Analysis Methods

| Method | What it assumes | Why it is useful |
| --- | --- | --- |
| Static analysis | The robot is stationary and all forces/moments balance. | Simple first check for standing poses and worst-case support loads. |
| Quasi-static analysis | The robot moves slowly enough that inertial effects are ignored at each instant. | Good for early actuator sizing because it captures pose-dependent torque without needing a full dynamics model. |
| Dynamic analysis | Link accelerations, body acceleration, impacts, and inertia are included. | Needed for aggressive locomotion, jumping, landing, and final validation. |
| Simulation/experiment | Multibody simulation or measured hardware data. | Best for validating controller behavior, contact loads, thermal limits, and real losses. |

For early robot design, quasi-static analysis is usually the most useful starting point. It is easy to audit, easy to recompute when dimensions change, and gives a reasonable baseline before adding safety factors, motor limits, gearbox efficiency, and dynamic validation.

## Resources To Add

- Static equilibrium and free-body diagram videos.
- Robot statics / Jacobian transpose resources.
- Actuator sizing videos or articles.
- Examples from quadruped actuator papers.

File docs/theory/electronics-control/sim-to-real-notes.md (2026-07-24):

---
title: Sim-to-real Notes
---

# Sim-to-real Notes

This page should explain the gap between simulation and hardware: modeling error, latency, contact, friction, actuator limits, and calibration.

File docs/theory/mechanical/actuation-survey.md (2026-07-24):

---
title: Actuation Survey
---

# Actuation Survey

Quadruped actuation is a tradeoff between torque density, speed, impact tolerance, efficiency, cost, controllability, and mechanical complexity. This page is the background survey for choosing and explaining the actuator architecture of this robot.

## Quick terminology

In legged-robot documentation, **proximal** means closer to the robot body and **distal** means farther from the body. The hip is proximal, the foot is distal, and the knee sits between the upper and lower leg links.

<figure className="figure--small">
  Quadruped leg terminology showing body, fore leg, hind leg, hip joint, thigh, knee joint, calf, and footpad
  <figcaption>Basic quadruped body and leg terminology. Source: figure from <a href="https://www.sciencedirect.com/science/article/abs/pii/S0022489825000151">this ScienceDirect paper</a>.</figcaption>
</figure>

For most quadruped legs:

- **Hip abduction/adduction** swings the leg sideways.
- **Hip flexion/extension** swings the leg forward and backward.
- **Knee flexion/extension** folds or extends the lower leg.
- **Upper leg / thigh / femur** usually means the link between hip pitch and knee.
- **Lower leg / calf / shank** usually means the link between knee and foot.

## Actuator families

| Actuation type | Typical idea | Strengths | Tradeoffs | Examples / references |
| --- | --- | --- | --- | --- |
| Direct electric drive | High-torque motor drives the joint with little or no reduction. | Backdrivable, simple torque control, low reflected inertia. | Heavy motors for high torque; often expensive. | Research actuators and quasi-direct-drive designs. |
| Quasi-direct-drive electric | High torque-density BLDC motor plus low-ratio transmission. | Good balance of torque, speed, backdrivability, and impact tolerance. | Needs careful motor, gearbox, thermal, and current-control design. | MIT Mini Cheetah and Ben Katz's modular actuator thesis. |
| High-ratio geared electric | Motor with large gearbox reduction. | Compact torque amplification and easy position holding. | Lower backdrivability, higher reflected inertia, poorer impact behavior unless torque sensing/compliance is added. | Many industrial/mobile robot joints. |
| Series elastic actuation | Elastic element between motor/transmission and output. | Force sensing through spring deflection, shock tolerance, compliance. | Extra mechanical volume, bandwidth limits, more modeling/control work. | ANYmal-style SEA literature, older legged platforms. |
| Hydraulic actuation | Hydraulic cylinders or rotary hydraulic actuators drive joints. | Very high force density and rugged dynamic motion. | Pumps, valves, fluid management, noise, maintenance, leakage risk, lower accessibility for a student build. | IIT HyQ hydraulic quadruped. |
| Pneumatic actuation | Compressed air drives cylinders or artificial muscles. | Naturally compliant and light at the actuator. | Harder precision control, air supply complexity, lower stiffness. | Soft robots and experimental legs. |

For our quadruped, the strongest practical candidate is usually **electric quasi-direct-drive**: BLDC motor, low-ratio transmission and current/torque control. This is the direction argued strongly by Ben Katz's thesis and the MIT Cheetah actuator literature.

## Leg transmission mechanisms

### Direct or coaxial rotary joints

The simplest architecture places a rotary actuator at each joint. It is easy to model and package conceptually, but knee and distal actuators can add leg inertia if they sit far from the body.

<figure>
  Quadruped CAD model with direct or coaxial rotary leg actuation
  <figcaption>Direct/coaxial rotary joint layout, where actuators sit near the corresponding leg joints.</figcaption>
</figure>

### Push-rod knee mechanism

In a push-rod leg, the knee motor is placed closer to the hip/body and drives the knee through a rod-linkage transmission. This keeps the heavy actuator mass proximal while still moving the lower leg. The tradeoff is that the knee torque and speed depend on linkage geometry, so the mechanical advantage changes through the workspace.

**Examples:** Unitree Go1 and Go2 style legs. The Observable inverse-kinematics page and Sketchfab model are especially useful visual references for the Go2 leg layout.

<figure>
  Push-rod quadruped leg mechanism with proximal knee actuation
  <figcaption>Push-rod style knee actuation, with the motor placed proximally and a linkage transmitting motion to the lower leg.</figcaption>
</figure>

### Ball screw / screw actuator mechanism

A rotary motor drives a screw, converting rotation into linear motion. That linear actuator then drives a linkage at the knee. This can produce large forces in a compact leg, but it adds screw/nut friction, efficiency losses, speed limits, and wear considerations.

**Example:** Boston Dynamics Spot-style screw actuator architecture. The Boston Dynamics patent describes a motor-driven screw shaft and translating nut/carrier inside the upper leg, coupled by a linkage to rotate the lower leg about the knee.

<figure>
  Ball screw actuator driving a robot leg linkage
  <figcaption>Ball-screw style linear actuation converting motor rotation into linkage motion at the leg.</figcaption>
</figure>

### Belt-driven knee mechanism

A belt transfers torque from a motor near the hip to a pulley at the knee. This keeps mass proximal and can be efficient, compact, and backdrivable, but belt tensioning, skipped teeth, pulley sizing, backlash, and belt wear become design concerns.

**Examples:** MIT Mini Cheetah-style legs and several Deep Robotics quadruped designs use compact electric actuators with belt/transmission layouts to keep distal inertia low.

<figure>
  Belt-driven quadruped leg transmission
  <figcaption>Belt-driven leg transmission with proximal actuation and routed torque to the lower leg.</figcaption>
</figure>

### Four-bar linkage leg

A four-bar leg uses a closed linkage to shape the foot path and transmit motion. It can package actuation neatly and create useful passive or compliant behavior, but the kinematics are less direct than a simple serial two-link leg and the torque transmission varies with pose.

**Examples:** four-bar research legs, including compliant/spring-assisted concepts.

## Mechanism examples

| Mechanism | Example robots / resources | Notes |
| --- | --- | --- |
| Push rod | [Unitree Go2 IK notebook](https://observablehq.com/@christophe-yamahata/inverse-kinematics-go2-robot), [Go2 leg Sketchfab model](https://sketchfab.com/models/d84607a0dc864921826cb092364d3990/embed) | Good visual reference for compact proximal actuation and knee linkage geometry. |
| Ball screw | [Spot video](https://www.youtube.com/watch?v=tfWbE_1eCZk), [Boston Dynamics screw actuator patent](https://patents.google.com/patent/US10253855B2/en), [ball screw leg video](https://www.youtube.com/watch?v=YrpHYPPWpIk) | Strong force packaging; useful to compare against Spot-style architecture. |
| Belt drive | [Ben Katz thesis](https://dspace.mit.edu/bitstream/handle/1721.1/118671/1057343368-MIT.pdf), [MIT Mini Cheetah article](https://news.mit.edu/2019/mit-mini-cheetah-first-four-legged-robot-to-backflip-0304), [Deep Robotics joints](https://www.deeprobotics.us/products/joints/) | Keeps moving mass close to the body and works well with quasi-direct-drive electric actuators. |
| Four bar | [Four-bar kinematic modeling paper](https://www.semanticscholar.org/paper/KINEMATIC-MODELING-OF-QUADRUPED-ROBOT-WITH-FOUR-BAR-Oak-Narwane/af2b230710d164cd3fc85b4caa0c05ced5aafb04), [4-bar compliant leg video](https://www.youtube.com/watch?v=bDxItdyQ3jc) | Useful when the linkage path/compliance is part of the design goal. |

## Core references

- Benjamin G. Katz, [A Low Cost Modular Actuator for Dynamic Robots](https://dspace.mit.edu/bitstream/handle/1721.1/118671/1057343368-MIT.pdf), MIT S.M. thesis, 2018.
- Patrick M. Wensing et al., [Proprioceptive Actuator Design in the MIT Cheetah](https://biomimetics.mit.edu/publications/4ebd1209-954e-4f9e-b64e-473e80b11318/), IEEE Transactions on Robotics, 2017.
- Jun He and Feng Gao, [Mechanism, Actuation, Perception, and Control of Highly Dynamic Multilegged Robots: A Review](https://cjme.springeropen.com/articles/10.1186/s10033-020-00485-9), Chinese Journal of Mechanical Engineering, 2020.
- Boston Dynamics, [Screw actuator for a legged robot](https://patents.google.com/patent/US10253855B2/en), US10253855B2.
- Christophe Yamahata, [Inverse Kinematics: Go2 Robot's Leg](https://observablehq.com/@christophe-yamahata/inverse-kinematics-go2-robot).

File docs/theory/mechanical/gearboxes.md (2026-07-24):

---
title: Gearboxes
---

# Gearboxes

Gearboxes sit between the motor and joint output. They reduce speed and multiply torque:

```text
output_torque = motor_torque * reduction_ratio * efficiency
output_speed  = motor_speed / reduction_ratio
```

For quadrupeds, the gearbox choice affects torque density, backdrivability, impact tolerance, backlash, efficiency, cost, and how easy the joint is to control.

## Common gearbox types

| Type | Basic idea | Pros | Cons |
| --- | --- | --- | --- |
| Planetary | Sun gear drives planet gears inside a ring gear. | Compact, common, good torque density, easy to source. | Backlash depends on quality, high ratios reduce backdrivability, multiple stages add complexity. |
| Cycloidal | Eccentric input drives a cycloidal disc against pins/rollers. | High reduction in small volume, good shock tolerance, strong torque capacity. | More complex geometry, can have vibration/ripple, precision manufacturing matters. |
| Harmonic | Wave generator flexes a spline against a circular spline. | Very high reduction, compact, low backlash. | Expensive, less backdrivable, flexspline fatigue risk under shock loads. |
| Worm | Screw-like worm drives a worm wheel. | Simple high reduction, compact right-angle drive, can be self-locking. | Low efficiency, heat generation, poor backdrivability, sliding wear. |

### Planetary gearbox

Planetary gearboxes are common in robotics because they package reduction compactly around the motor axis.

<div className="figure-grid figure-grid--two figure-grid--compact">
  <figure>
    Planetary gearbox labeled with sun gear, planet gears, ring gear, and carrier
    <figcaption>Planetary gearbox layout: sun gear, planet gears, ring gear, and carrier.</figcaption>
  </figure>
  <figure>
    Animated planetary gear motion
    <figcaption>Planetary gear motion.</figcaption>
  </figure>
</div>

### Cycloidal drive

Cycloidal drives use an eccentric input to move a cycloidal disc against pins or rollers, producing a large reduction in a compact volume.

<div className="figure-grid figure-grid--two figure-grid--compact">
  <figure>
    Exploded cycloidal drive with input shaft, eccentric bearing, cycloidal disk, ring gear, and output shaft
    <figcaption>Cycloidal drive components: eccentric input, cycloidal disc, ring pins/rollers, and output pins.</figcaption>
  </figure>
  <figure>
    Animated cycloidal drive motion
    <figcaption>Cycloidal drive motion.</figcaption>
  </figure>
</div>

### Harmonic drive

Harmonic drives use a wave generator to flex a spline into a circular spline, creating high reduction with very low backlash.

<div className="figure-grid figure-grid--two figure-grid--compact">
  <figure>
    Harmonic drive showing circular spline, flex spline, and wave generator
    <figcaption>Harmonic drive components: circular spline, flex spline, and wave generator.</figcaption>
  </figure>
  <figure>
    Animated harmonic drive motion
    <figcaption>Harmonic drive motion.</figcaption>
  </figure>
</div>

### Worm gearbox

Worm gearboxes use a screw-like worm to drive a worm wheel. They can produce high reductions and may be self-locking, but the sliding contact makes efficiency and heat important concerns.

<div className="figure-grid figure-grid--two figure-grid--compact">
  <figure>
    Cutaway worm gearbox showing worm and worm wheel
    <figcaption>Worm gearbox layout with worm and worm wheel.</figcaption>
  </figure>
  <figure>
    Animated worm gear motion
    <figcaption>Worm gear motion.</figcaption>
  </figure>
</div>

## Quadruped-specific tradeoff

Dynamic quadrupeds usually benefit from joints that can feel and react to ground impacts. That is why many modern electric quadrupeds avoid very high reductions and instead use direct or quasi-direct-drive actuators, belts, or moderate-ratio gearboxes.

Higher reduction helps torque, but it usually hurts:

- backdrivability,
- reflected inertia,
- impact tolerance,
- force-control bandwidth,
- mechanical transparency.

Lower reduction helps dynamic behavior, but demands a stronger motor and higher phase current.

## References and tools

### Planetary

- [Planetary gears explained](https://youtu.be/Ho4AniHtgxM?si=m1kBRgKtOiZX1tb_)
- [Planetary gearbox animation](https://youtu.be/9CDH4NMT_Pc?si=lIJQrVTVulQ4AMoQ)
- [Gear Generator](https://geargenerator.com/beta/) for quick visual gear sketches.

### Cycloidal

- [Cycloidal disc design video](https://m.youtube.com/watch?v=guvatctnjww&pp=ygUcSG93IHRvIGRlc2lnbiBjeWNsb2lkYWwgZGlzaw%3D%3D)
- [Cycloidal drive explanation](https://youtu.be/OsS9-FzKN6s?si=6UzUr6US2mjOdzF2)
- [Cycloidal drive animation](https://youtu.be/eM-8IO_mNIM?si=bPmpjyQm1xUHWZJ3)
- [Building a Cycloidal Drive with SOLIDWORKS](https://blog-assets.solidworks.com/uploads/sites/3/Building-a-Cycloidal-Drive-with-SOLIDWORKS.pdf)

### Harmonic

- [Harmonic drive explanation](https://youtu.be/IXmCze1GsGU?si=k866qfZEKOZKAqwM)

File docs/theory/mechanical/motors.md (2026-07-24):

---
title: Motors
---

# Motors

After estimating joint torque requirements, the next question is: what motor can produce that torque and speed without overheating or making the leg hard to control?

## Common motor types

| Type | Basic idea | Pros | Cons |
| --- | --- | --- | --- |
| Brushed DC motor | Current through brushes commutates the rotor mechanically. | Simple, cheap, easy to drive. | Brush wear, lower efficiency, limited power density, electrical noise. |
| Servo motor | Motor plus gearbox, controller, and position feedback in one package. | Easy position control, simple interface, beginner-friendly. | Often low backdrivability, limited torque/speed transparency, hard to do high-performance force control. |
| Stepper motor | Moves in discrete steps using energized phases. | Simple position control without encoder in low-speed applications, high holding torque. | Inefficient at high speed, can skip steps, poor impact behavior, not ideal for dynamic legs. |
| BLDC motor | Electronic commutation drives a permanent-magnet rotor. | High efficiency, high power density, good torque control, long life. | Needs motor driver, sensing/estimation, current control, and more careful tuning. |

<div className="figure-grid figure-grid--four">
  <figure>
    Small brushed DC motor
    <figcaption>Brushed DC motor</figcaption>
  </figure>
  <figure>
    Small hobby servo motor
    <figcaption>Servo motor</figcaption>
  </figure>
  <figure>
    Stepper motor
    <figcaption>Stepper motor</figcaption>
  </figure>
  <figure>
    BLDC outrunner motor
    <figcaption>BLDC motor</figcaption>
  </figure>
</div>

## Why BLDCs are common in good quadrupeds

Modern electric quadrupeds usually need high torque density, fast torque response, and good efficiency. BLDC motors fit this well, especially when paired with low or moderate reduction transmissions.

Compared to servos or steppers, BLDC-based actuators can be:

- lighter for the same power,
- more efficient,
- better for torque/current control,
- more suitable for dynamic impacts,
- easier to make backdrivable with low-ratio transmissions.

This is why many research and commercial quadrupeds use custom BLDC actuator modules instead of hobby servos or steppers.

## Why low-KV pancake BLDCs are useful

Legged robots often use **low-KV pancake BLDC motors**: wide, flat outrunner motors with a relatively large diameter and low speed constant.

<figure className="figure--small">
  Low-KV pancake BLDC motor
  <figcaption>Low-KV pancake BLDC motor: large diameter, short axial length, and high torque density for its package.</figcaption>
</figure>

They are useful because:

- **Low `Kv` usually means higher `Kt`**, so the motor produces more torque per ampere.
- **Large diameter gives a bigger magnetic moment arm**, which helps torque density.
- **Flat packaging works well inside compact joint modules.**
- **High pole count and outrunner geometry help produce usable torque at lower speeds.**
- **They pair well with low-ratio reductions**, keeping the actuator more backdrivable and impact tolerant.

The tradeoff is that they still need high-current motor drivers, good thermal design, and careful control.

## Key motor parameters

| Parameter | Why it matters |
| --- | --- |
| Peak torque | Short-duration torque for push-off, recovery, and disturbance handling. |
| Continuous torque | Torque the motor can hold thermally without overheating. |
| Torque constant `Kt` | Converts phase current into motor torque. |
| Velocity constant `Kv` | Relates motor speed to voltage; helps estimate speed limits. |
| Max current | Electrical limit from motor windings, driver, battery, and thermal design. |
| Phase resistance | Affects copper losses and heating: `P_loss = I^2 R`. |
| Rotor inertia | Affects reflected inertia and impact behavior. |
| Mass | Directly affects robot mass and leg inertia. |

## Basic sizing chain

```text
required_joint_torque -> transmission ratio -> required_motor_torque -> required_current
```

With a gearbox, belt, or linkage reduction:

```text
motor_torque = joint_torque / (reduction_ratio * efficiency)
motor_current = motor_torque / Kt
```

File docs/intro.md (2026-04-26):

---
id: intro
title: Project Overview
sidebar_position: 1
slug: /intro
---

# ERC Quadruped

This documentation is the handoff point for the ERC-BPGC quadruped project: the hardware, electronics, code, experiments, and open questions needed for the next team to continue from the current state instead of rediscovering it from scratch.

The site is intentionally split by subsystem so a new contributor can enter from the part they care about:

- **Mechanical:** CAD, frame architecture, links, joints, assembly notes, manufacturing constraints.
- **Electronics:** power, wiring, motor drivers, compute, sensors, connectors, safety checks.
- **Software:** code map, scripts, dependencies, runtime flow, logging, test utilities.
- **Controls:** kinematics, gait logic, motor control, simulation-to-hardware notes.
- **Simulation:** Genesis/MJCF/URDF assets and training or evaluation workflows.

The first pass of these docs is a scaffold. The goal is to keep filling each page with source links, photos, diagrams, commands, known failure modes, and design reasoning.

## Repository layout

```text
Quadruped/
  docs/                  Documentation source for this site
  src/                   Docusaurus homepage and styling
  static/                Images and static assets for the site
  Genesis/               Simulation and project source material
  README.md              GitHub landing page
```

## What good looks like

Every mature page should eventually answer five questions:

1. What is this subsystem responsible for?
2. Where are the source files, CAD files, schematics, or scripts?
3. How do I build, assemble, run, or test it?
4. What is known to work, and what is still unreliable?
5. What should the next contributor try first?

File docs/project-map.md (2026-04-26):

---
id: project-map
title: Project Map
sidebar_position: 2
---

# Project Map

Use this page as the index of all major project artifacts. Keep links here short and direct so future contributors can quickly find the thing they need.

## Current source areas

| Area | Path | Notes |
| --- | --- | --- |
| Simulation experiments | `Genesis/Quadruped_local/` | Local quadruped models, scripts, configs, trained model files, and meshes. |
| Genesis simulator source | `Genesis/genesis/` | Vendored or local copy of the Genesis simulator code. |
| Simulation examples | `Genesis/examples/` | Upstream-style examples and locomotion references. |
| Docs site | `docs/`, `src/`, `static/` | This Docusaurus documentation site. |

## Artifact inventory to add

- CAD source files and export locations.
- Electronics schematics, PCB files, wiring diagrams, and BOMs.
- Motor, driver, battery, compute, and sensor datasheets.
- Firmware and control code entry points.
- Photos and videos of each robot revision.
- Experiment logs, dead ends, and next-step notes.

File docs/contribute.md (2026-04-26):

---
title: Contributing
---

# Contributing

Documentation should move with the project. If you change hardware, wiring, software, or experimental assumptions, update the relevant page in the same pull request.

## Writing style

- Prefer concrete steps over vague descriptions.
- Link to files instead of saying "in the code".
- Add photos, diagrams, or screenshots when they reduce ambiguity.
- Record failed approaches when they would save future time.
- Put TODOs where knowledge is missing, but make them specific.

## Local docs workflow

```bash
nvm use
npm install
npm run start
```

The local site runs at `http://localhost:3000/Quadruped/`.

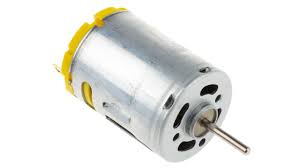
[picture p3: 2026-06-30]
docs/mechanical/assets/motors/DC.jpeg

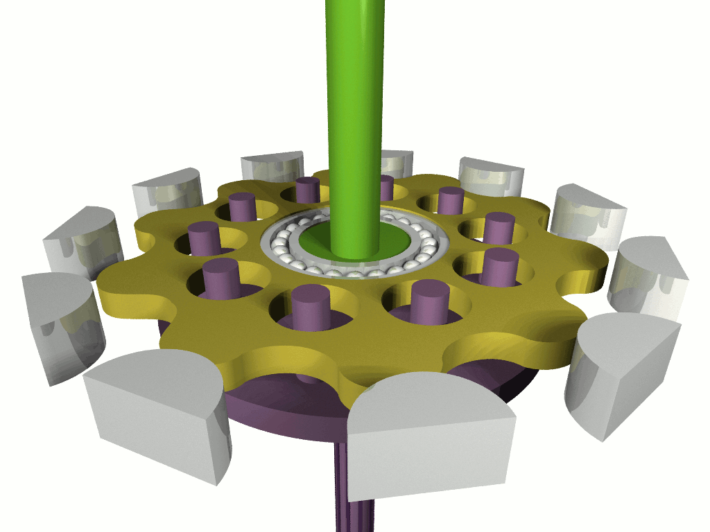
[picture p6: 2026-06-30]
docs/mechanical/assets/gearboxes/cycloidal_drive.gif

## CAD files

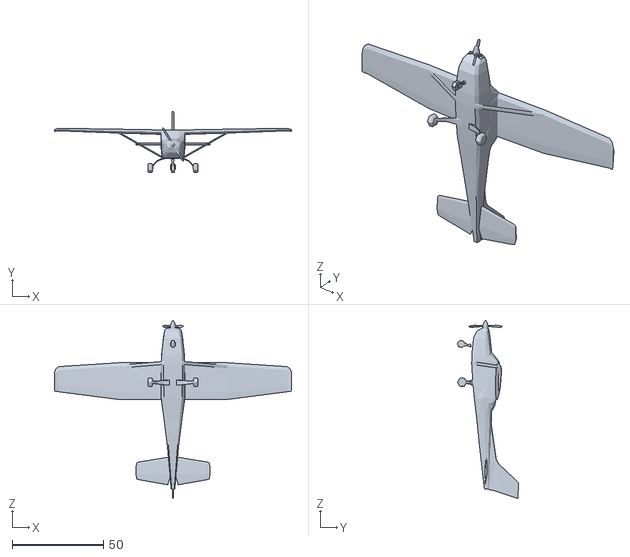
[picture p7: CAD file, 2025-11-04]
Genesis/genesis/assets/meshes/Airplane/airplane.obj
130.1 x 33.6 x 97.9

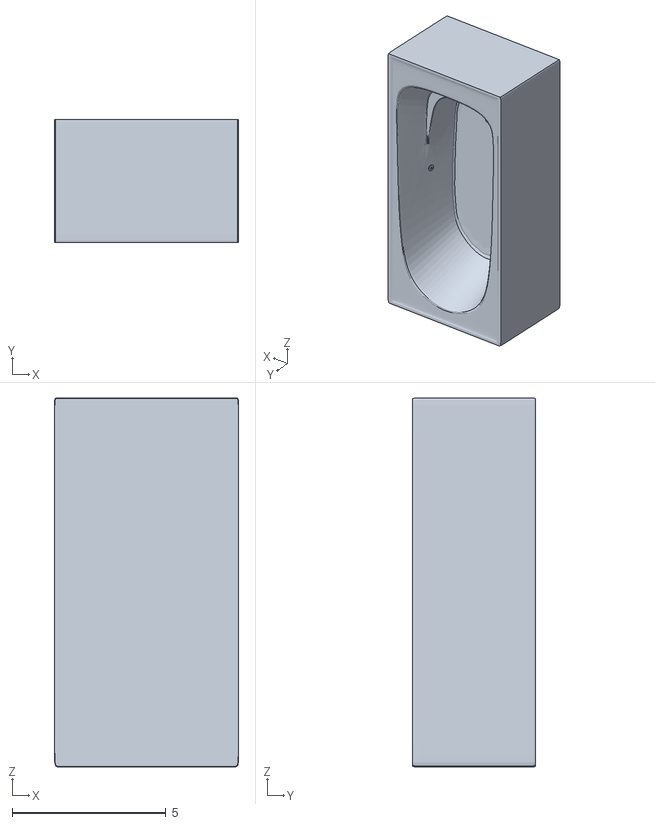
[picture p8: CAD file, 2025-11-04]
Genesis/genesis/assets/meshes/bathtub/bathtub.obj
6.00 x 4.00 x 12.0
Bathtub_lambert1_0
Stophole_lambert1_0
Water2_lambert1_0
Water1_lambert1_0
Water_lambert1_0
Hole_lambert1_0

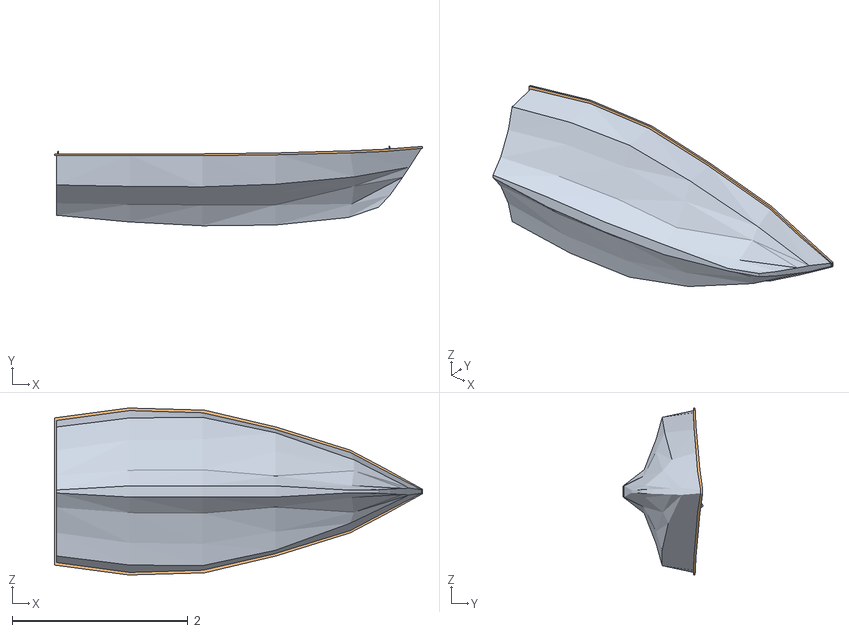
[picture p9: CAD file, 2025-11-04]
Genesis/genesis/assets/meshes/boat/boat.obj
4.18 x 0.905 x 1.90

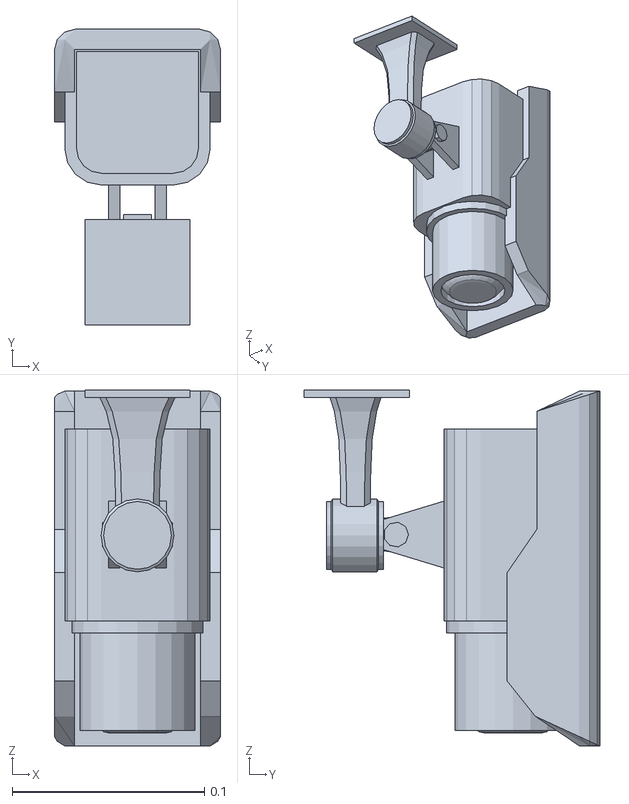
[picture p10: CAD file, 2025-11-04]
Genesis/genesis/assets/meshes/camera/camera.obj
0.0864 x 0.154 x 0.185

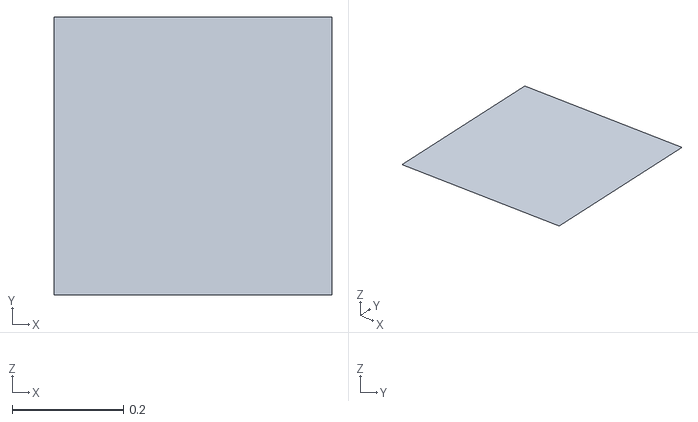
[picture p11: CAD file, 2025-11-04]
Genesis/genesis/assets/meshes/cloth.obj
0.5 x 0.5 x 0

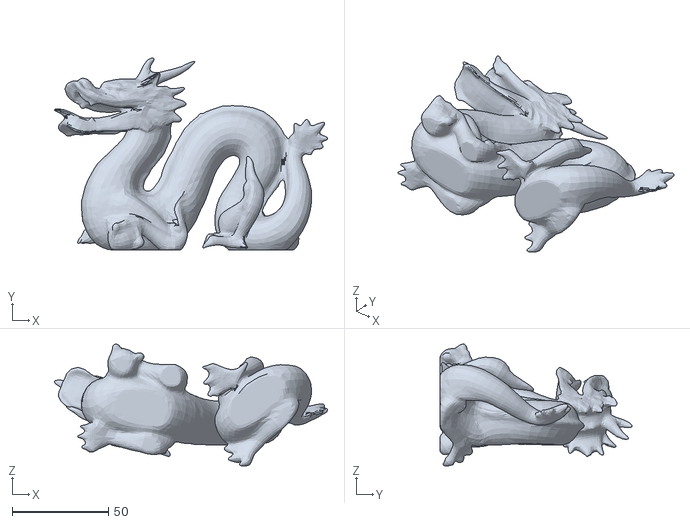
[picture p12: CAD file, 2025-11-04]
Genesis/genesis/assets/meshes/dragon/dragon.obj
141.5 x 99.6 x 63.2

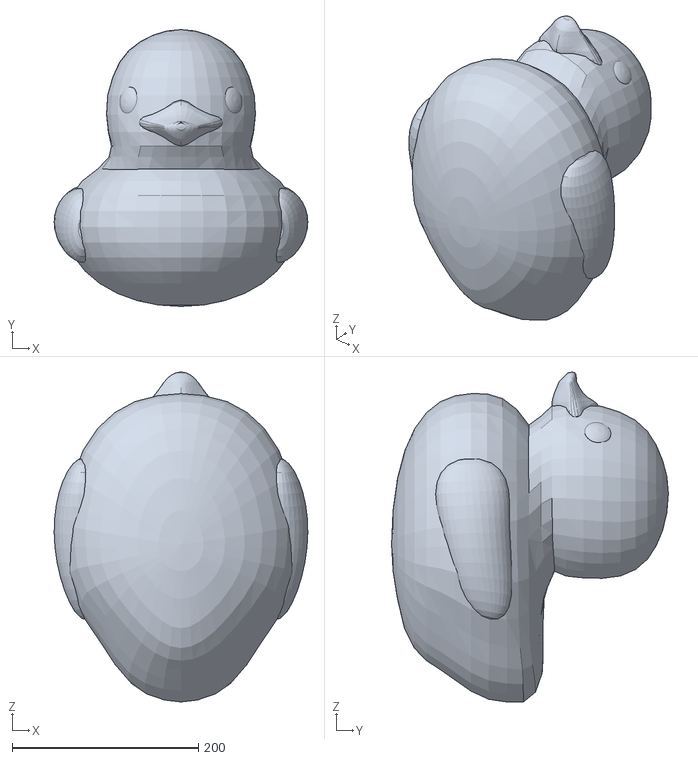
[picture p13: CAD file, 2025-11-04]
Genesis/genesis/assets/meshes/duck/duck.obj
272.3 x 297.3 x 354.3

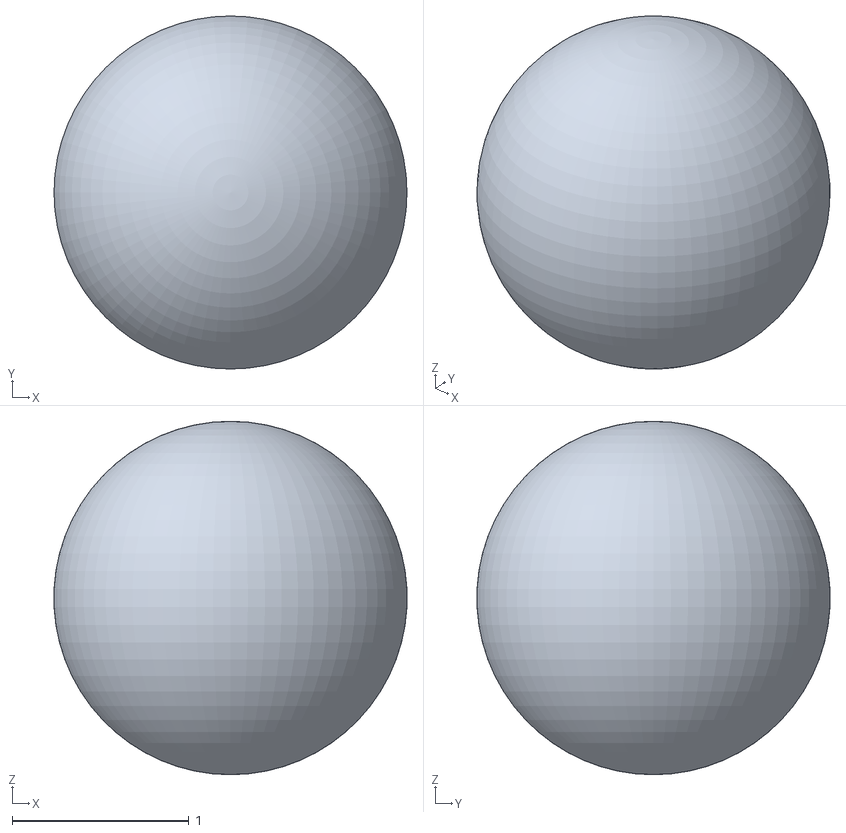
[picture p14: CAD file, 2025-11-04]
Genesis/genesis/assets/meshes/env_sphere/env_sphere.obj
2.00 x 2.00 x 2.00

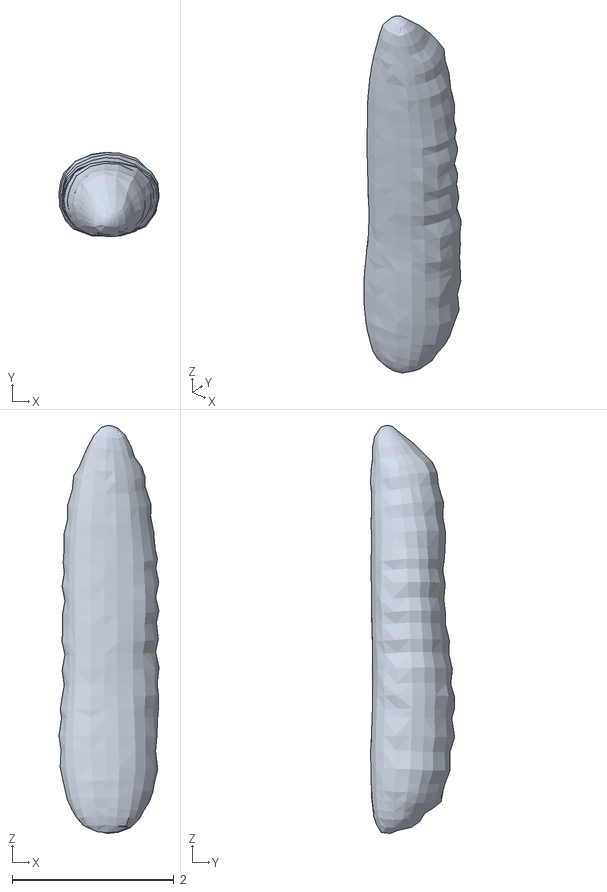
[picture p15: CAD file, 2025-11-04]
Genesis/genesis/assets/meshes/worm/worm.obj
1.24 x 1.04 x 5.04

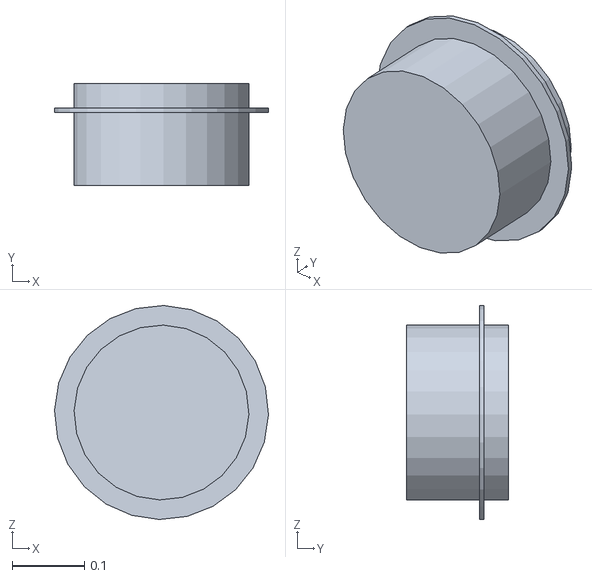
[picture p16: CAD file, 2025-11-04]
Genesis/genesis/assets/urdf/3763/textured_objs/original-1.obj
0.296 x 0.141 x 0.296

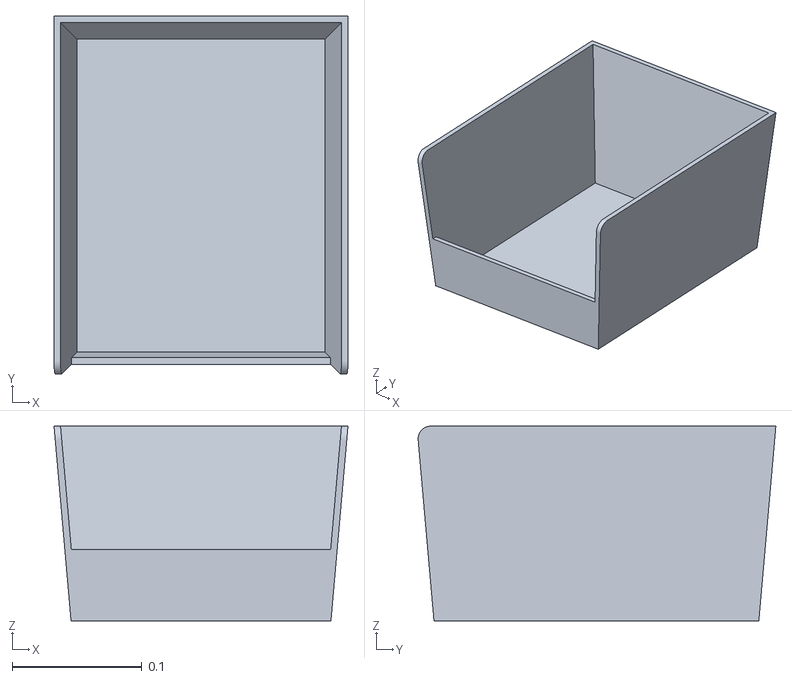
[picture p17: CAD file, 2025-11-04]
Genesis/genesis/assets/urdf/blue_box/assets/part_1.stl
0.226 x 0.275 x 0.15

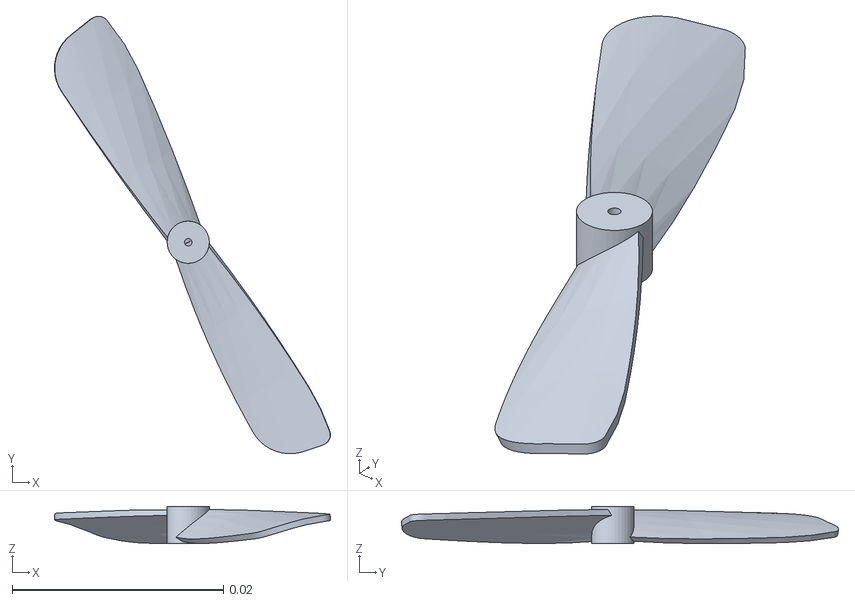
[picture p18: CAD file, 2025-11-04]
Genesis/genesis/assets/urdf/drones/propeller3.obj
0.0262 x 0.0415 x 0.00352

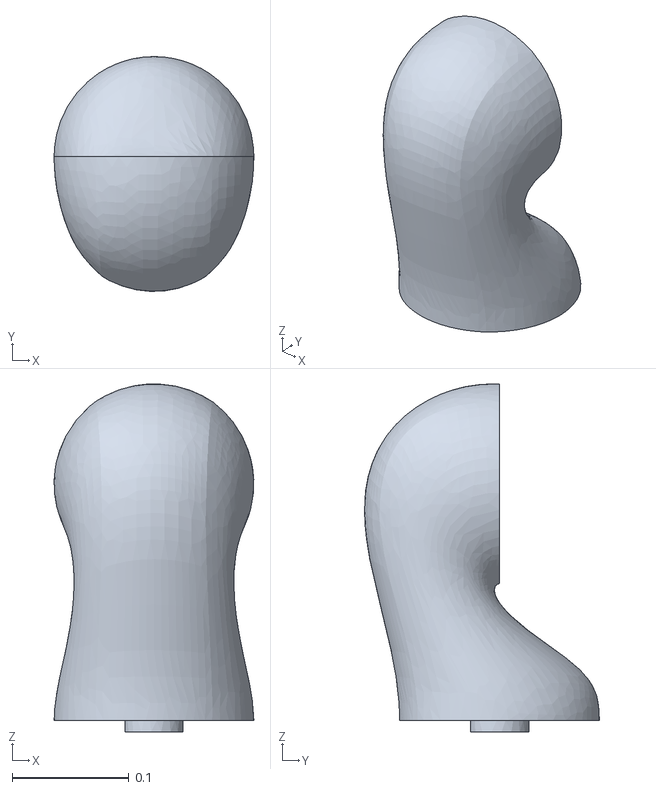
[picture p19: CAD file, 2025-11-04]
Genesis/genesis/assets/urdf/kuka_iiwa/meshes/link_1.stl
0.171 x 0.201 x 0.298

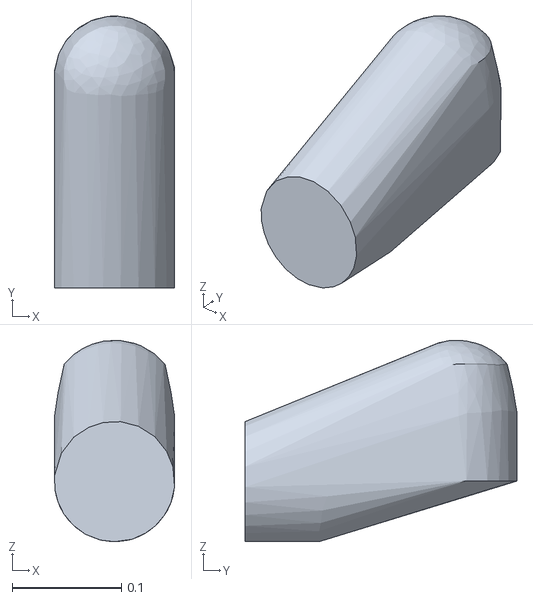
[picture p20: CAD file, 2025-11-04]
Genesis/genesis/assets/urdf/panda_bullet/meshes/collision/link2.obj
0.11 x 0.249 x 0.185

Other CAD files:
Genesis/genesis/assets/urdf/3763/point_sample/sample-points-all-pts-nor-rgba-10000.ply
Genesis/genesis/assets/urdf/panda_bullet/meshes/visual/link4.obj
Genesis/genesis/assets/urdf/plane/plane100.obj
Genesis/genesis/assets/urdf/shadow_hand/meshes/collision/palm.stl
Genesis/Quadruped_local/meshes/FL_calf.STL
Genesis/Quadruped_local/meshes/FL_thigh.STL
Genesis/Quadruped_local/meshes/FR_calf.STL
Genesis/Quadruped_local/meshes/FR_thigh.STL
Genesis/Quadruped_local/meshes/base_link.STL
Genesis/Quadruped_local/meshes_old/FL_calf.STL
Genesis/Quadruped_local/meshes_old/FL_thigh.STL
Genesis/Quadruped_local/meshes_old/FR_calf.STL
Genesis/Quadruped_local/meshes_old/FR_thigh.STL
Genesis/Quadruped_local/meshes_old/RL_calf.STL
Genesis/Quadruped_local/meshes_old/RL_thigh.STL
Genesis/Quadruped_local/meshes_old/RR_calf.STL
Genesis/Quadruped_local/meshes_old/RR_thigh.STL
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

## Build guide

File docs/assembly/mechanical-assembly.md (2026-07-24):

---
title: Mechanical Assembly
---

# Mechanical Assembly

This page should walk through how to physically assemble the robot without relying on memory or guesswork.

## Fill this first

- Required tools and fasteners.
- Assembly order.
- Bearing/shaft installation notes.
- Torque specs where known.
- Photos for each major step.

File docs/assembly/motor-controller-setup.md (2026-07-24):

---
title: Motor Controller Setup
---

# Motor Controller Setup

This page should document how to configure each motor controller before it is installed or used on the robot.

## Fill this first

- Flashing/setup steps.
- Motor and encoder calibration.
- Current and velocity limits.
- CAN IDs or device IDs.
- Safe bench-test procedure.

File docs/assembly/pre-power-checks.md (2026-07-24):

---
title: Pre-power Checks
---

# Pre-power Checks

This page should be the checklist before applying power to the robot.

## Fill this first

- Mechanical inspection.
- Polarity and continuity checks.
- Battery and fuse checks.
- Driver configuration checks.
- Emergency-stop and isolation checks.

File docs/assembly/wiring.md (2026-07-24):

---
title: Wiring
---

# Wiring

This page should show how the robot is wired in the real build: harness routes, connector orientation, cable labels, and checks before power is applied.

## Fill this first

- Wiring harness map.
- Connector photos and pinouts.
- Cable routing and strain relief.
- Driver, sensor, compute, and power connections.
- Continuity checks.

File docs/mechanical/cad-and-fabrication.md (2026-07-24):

---
title: CAD and Fabrication
---

# CAD and Fabrication

This page should be the map from documentation to real CAD/manufacturing files.

## Fill this first

- Canonical CAD location.
- Exported STEP/STL/DXF locations.
- Materials and manufacturing processes.
- Print/machining settings where relevant.
- Revision notes and known fabrication issues.

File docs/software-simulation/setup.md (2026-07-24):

---
title: Setup
---

# Setup

This page should document how to set up the software environment for simulation, testing, and robot operation.

## Fill this first

- OS and dependency assumptions.
- Python/Node/ROS/toolchain versions.
- Install commands.
- Environment variables.
- Sanity-check commands.

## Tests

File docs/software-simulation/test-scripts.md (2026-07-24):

---
title: Test Scripts
---

# Test Scripts

This page should list the scripts used to test motors, sensors, kinematics, simulation, and walking experiments.

## Fill this first

- Script name and path.
- What hardware must be connected.
- Required arguments/config files.
- Expected output.
- Failure modes.

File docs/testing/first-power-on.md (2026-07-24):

---
title: First Power-on
---

# First Power-on

This page should describe the safest first-power sequence after assembly or major maintenance.

## Fill this first

- Bench setup.
- Current-limited supply settings.
- Expected LEDs/logs.
- What to measure before enabling motors.
- Stop conditions.

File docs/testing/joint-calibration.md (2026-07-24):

---
title: Joint Calibration
---

# Joint Calibration

This page should document how joint zero positions, signs, limits, and encoder offsets are calibrated.

## Fill this first

- Mechanical zero definition.
- Encoder offset procedure.
- Joint direction checks.
- Soft and hard limits.
- Calibration files or scripts.

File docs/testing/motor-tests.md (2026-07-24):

---
title: Motor Tests
---

# Motor Tests

This page should document the motor-level tests used before attempting joint or walking tests.

## Fill this first

- Single motor spin test.
- Encoder direction check.
- Current control sanity check.
- Temperature/current monitoring.
- Common failure symptoms.

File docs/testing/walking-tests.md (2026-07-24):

---
title: Walking Tests
---

# Walking Tests

This page should document the staged path from supported leg motion to actual walking tests.

## Fill this first

- Test stand or support setup.
- Low-level joint tests.
- Standing test.
- Weight shifting.
- First stepping/walking experiments.
- Logs and videos to capture.

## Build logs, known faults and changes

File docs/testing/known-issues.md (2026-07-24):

---
title: Known Issues
---

# Known Issues

This page should stay brutally honest. If something is fragile, undocumented, hacked together, or only works under certain conditions, record it here.

## Fill this first

- Current hardware issues.
- Current software/control issues.
- Risky assumptions.
- Temporary fixes.
- Suggested next repairs or redesigns.

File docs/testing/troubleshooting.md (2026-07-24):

---
title: Troubleshooting
---

# Troubleshooting

This page should collect common failures and the fastest checks for each one.

## Fill this first

- Power issues.
- Driver communication issues.
- Encoder direction or offset issues.
- Motor heating or oscillation.
- Software/runtime errors.
- Mechanical looseness or binding.

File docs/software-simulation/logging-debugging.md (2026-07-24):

---
title: Logging / Debugging
---

# Logging / Debugging

This page should explain how to capture logs, inspect robot state, and debug failed tests.

## Fill this first

- Log file locations.
- Telemetry topics or streams.
- Plotting/analysis tools.
- Debug flags.
- Useful known-good logs.

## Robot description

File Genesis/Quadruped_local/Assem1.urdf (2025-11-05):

<?xml version="1.0" encoding="utf-8"?>
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
<robot name="Assem1">
  
  <mujoco>
    <compiler meshdir="meshes/" balanceinertia="true" discardvisual="false"/>
  </mujoco>
  
  <link name="base_link">
    <inertial>
      <origin xyz="-0.00108624006399256 0.0713870619430856 2.53716713501436E-06" rpy="0 0 0" />
      <mass value="8.71058047337637" />
      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
    </inertial>
    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
  </link>
  <link name="FL_thigh">
    <inertial>
      <origin xyz="-0.000432342593442769 0.0401453710641275 -0.0510720208550018" rpy="0 0 0" />
      <mass value="1.1557667485892" />
      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
    </inertial>
    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
  </link>
  <joint name="FL_thigh_joint" type="revolute">
    <origin xyz="0.21155 0.09 -0.179" rpy="-1.5708 -0.65858 1.5708" />
    <parent link="base_link" />
    <child link="FL_thigh" />
    <axis xyz="0 0 1" />
    <limit lower="0" upper="0" effort="0" velocity="0" />
  </joint>
  <link name="FL_calf">
    <inertial>
      <origin xyz="-1.51412754556546E-09 -0.0322976835833013 0.16607046385254" rpy="0 0 0" />
      <mass value="0.0721119079044262" />
      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
    </inertial>
    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
  </link>
  <joint name="FL_calf_joint" type="revolute">
    <origin xyz="0 0.24545 -0.054447" rpy="0 1.5708 0" />
    <parent link="FL_thigh" />
    <child link="FL_calf" />
    <axis xyz="-1 0 0" />
    <limit lower="0" upper="0" effort="0" velocity="0" />
  </joint>
  <link name="FR_thigh">
    <inertial>
      <origin xyz="0.00108738632674912 0.0401453433357715 0.0508399694213053" rpy="0 0 0" />
      <mass value="1.15576747324556" />
      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
    </inertial>
    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
  </link>
  <joint name="FR_thigh_joint" type="revolute">
    <origin xyz="-0.211552777848526 0.09 -0.179" rpy="-1.57079632679489 -0.664081076227596 1.57079632679489" />
    <parent link="base_link" />
    <child link="FR_thigh" />
    <axis xyz="0 0 1" />
    <limit lower="0" upper="0" effort="0" velocity="0" />
  </joint>
  <link name="FR_calf">
    <inertial>
      <origin xyz="-1.5141E-09 -0.032298 0.16607" rpy="0 0 0" />
      <mass value="0.072112" />
      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
    </inertial>
    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
  </link>
  <joint name="FR_calf_joint" type="revolute">
    <origin xyz="0 0.245452180138539 0.0544472221514732" rpy="0 1.5707963267949 0" />
    <parent link="FR_thigh" />
    <child link="FR_calf" />
    <axis xyz="-1 0 0" />
    <limit lower="0" upper="0" effort="0" velocity="0" />
  </joint>
  <link name="RL_thigh">
    <inertial>
      <origin xyz="-0.000432342617895792 0.0401453716726288 -0.0510720208638447" rpy="0 0 0" />
      <mass value="1.15576675553714" />
      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
    </inertial>
    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
  </link>
  <joint name="RL_thigh_joint" type="revolute">
    <origin xyz="0.21155 0.09 0.179" rpy="-1.5708 -0.67935 1.5708" />
    <parent link="base_link" />
    <child link="RL_thigh" />
    <axis xyz="0 0 1" />
    <limit lower="0" upper="0" effort="0" velocity="0" />
  </joint>
  <link name="RL_calf">
    <inertial>
      <origin xyz="-1.51412754556546E-09 -0.0322976835833007 0.16607046385254" rpy="0 0 0" />
      <mass value="0.0721119079044264" />
      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
    </inertial>
    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
  </link>
  <joint name="RL_calf_joint" type="revolute">
    <origin xyz="0 0.24545 -0.054447" rpy="0 1.5708 0" />
    <parent link="RL_thigh" />
    <child link="RL_calf" />
    <axis xyz="-1 0 0" />
    <limit lower="0" upper="0" effort="0" velocity="0" />
  </joint>
  <link name="RR_thigh">
    <inertial>
      <origin xyz="0.00108738632674912 0.0401453433357715 0.0508399694213053" rpy="0 0 0" />
      <mass value="1.15576747324556" />
      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
    </inertial>
    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
  </link>
  <joint name="RR_thigh_joint" type="revolute">
    <origin xyz="-0.211552777848526 0.09 0.179" rpy="-1.57079632679489 -0.678502499051583 1.57079632679489" />
    <parent link="base_link" />
    <child link="RR_thigh" />
    <axis xyz="0 0 1" />
    <limit lower="0" upper="0" effort="0" velocity="0" />
  </joint>
  <link name="RR_calf">
    <inertial>
      <origin xyz="1.5141227160953E-09 -0.0322976835840128 -0.166070463852405" rpy="0 0 0" />
      <mass value="0.0721119079044261" />
      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
    </inertial>
    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
  </link>
  <joint name="RR_calf_joint" type="revolute">
    <origin xyz="0 0.245452180138539 0.0544472221514731" rpy="3.14159263868863 -1.5707963267949 0" />
    <parent link="RR_thigh" />
    <child link="RR_calf" />
    <axis xyz="-1 0 0" />
    <limit lower="0" upper="0" effort="0" velocity="0" />
  </joint>
</robot>

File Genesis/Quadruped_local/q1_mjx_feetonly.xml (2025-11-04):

<mujoco model="kutta">
  <compiler angle="radian" meshdir="meshes/" autolimits="true"/>

  <option iterations="1" ls_iterations="5" timestep="0.004" integrator="Euler">
    <flag eulerdamp="disable"/>
  </option>

  <default>
    <default class="kutta">
      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
      <joint axis="0 0 1" armature="0.005" damping="0.5"/>
      <position forcerange="-23.7 23.7" inheritrange="1" kp="35"/>
      <default class="thigh">
        <joint range="-0.9 0.67" frictionloss="0.3"/>
      </default>
      <default class="calf">
        <joint range="-0.5 0.5" frictionloss="1.0"/>
        <position forcerange="-35.55 35.55"/>
      </default>
      <default class="visual">
        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
      </default>
      <default class="collision">
        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
        <default class="trunk">
          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
        </default>
        <default class="thigh_col_right">
          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
        </default>
        <default class="thigh_col_left">
          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
        </default>
        <default class="calf_col">
          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
        </default>
        <default class="foot">
          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
        </default>
      </default>
    </default>
  </default>

  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

  <worldbody>
    <body name="trunk" pos="0 0 0.6" quat="0.7071 -0.7071 0 0" childclass="kutta">
      <camera name="track" pos="0.846 -1.3 0.316" xyaxes="0.866 0.500 0.000 -0.171 0.296 0.940" mode="trackcom"/>
      <camera name="top" pos="-1 0 1" xyaxes="0 -1 0 0.7 0 0.7" mode="trackcom"/>
      <camera name="side" pos="0 -1 .3" xyaxes="1 0 0 0 1 2" mode="trackcom"/>
      <camera name="back" pos="-1 0 .3" xyaxes="0 -1 0 1 0 2" mode="trackcom"/>
      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
      <inertial pos="0 0 0" mass="20.0" diaginertia="0.1 0.1 0.05"/>
      <freejoint/>
      
      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
      <body name="FL_thigh" pos="0.211553 0.09 -0.179" quat="0.634822 -0.31145 -0.634822 0.31145">
        <inertial pos="-0.000817907 0.0310806 -0.0509014" quat="0.393902 0.389492 -0.600379 0.576786" mass="1.55" diaginertia="0.00261662 0.00260068 0.00123196"/>
        <joint class="thigh" name="FL_thigh_joint"/>
        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
        <body name="FL_calf" pos="0 0.245452 -0.0544472" quat="0.707107 0 0.707107 0">
          <inertial pos="-1.51413e-09 -0.0322977 0.16607" quat="0.703848 0.0678076 -0.0678076 0.703848" mass="0.25" diaginertia="0.000849475 0.000848789 1.70367e-05"/>
          <joint class="calf" name="FL_calf_joint" axis="-1 0 0"/>
          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
        </body>
      </body>
      
      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
      <body name="FR_thigh" pos="-0.211553 0.09 -0.179" quat="0.635676 -0.309703 -0.635676 0.309703">
        <inertial pos="0.000777694 0.0310806 0.050662" quat="0.378108 0.389847 -0.582841 0.604442" mass="1.55" diaginertia="0.0026164 0.00260097 0.00123189"/>
        <joint class="thigh" name="FR_thigh_joint"/>
        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
        <body name="FR_calf" pos="0 0.245452 0.0544472" quat="0.707107 0 0.707107 0">
          <inertial pos="-1.51412e-09 -0.0322977 0.16607" quat="0.703848 0.0678076 -0.0678076 0.703848" mass="0.25" diaginertia="0.000849475 0.000848789 1.70367e-05"/>
          <joint class="calf" name="FR_calf_joint" axis="-1 0 0"/>
          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
        </body>
      </body>
      
      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
      <body name="RL_thigh" pos="0.211553 0.09 0.179" quat="0.638021 -0.304842 -0.638021 0.304842">
        <inertial pos="-0.000817907 0.0310806 -0.0509014" quat="0.393902 0.389492 -0.600379 0.576786" mass="1.55" diaginertia="0.00261662 0.00260068 0.00123196"/>
        <joint class="thigh" name="RL_thigh_joint"/>
        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
        <body name="RL_calf" pos="0 0.245452 -0.0544472" quat="0.707107 0 0.707107 0">
          <inertial pos="-1.51413e-09 -0.0322977 0.16607" quat="0.703848 0.0678076 -0.0678076 0.703848" mass="0.25" diaginertia="0.000849475 0.000848789 1.70367e-05"/>
          <joint class="calf" name="RL_calf_joint" axis="-1 0 0"/>
          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
        </body>
      </body>
      
      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
      <body name="RR_thigh" pos="-0.211553 0.09 0.179" quat="0.637893 -0.305111 -0.637893 0.305111">
        <inertial pos="0.000777694 0.0310806 0.050662" quat="0.378108 0.389847 -0.582841 0.604442" mass="1.55" diaginertia="0.0026164 0.00260097 0.00123189"/>
        <joint class="thigh" name="RR_thigh_joint"/>
        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
        <body name="RR_calf" pos="-0 0.245452 0.0544472" quat="0.707107 0 0.707107 0">
          <inertial pos="1.51412e-09 -0.0322977 -0.16607" quat="0.703848 -0.0678076 0.0678076 0.703848" mass="0.25" diaginertia="0.000849475 0.000848789 1.70367e-05"/>
          <joint class="calf" name="RR_calf_joint" axis="-1 0 0"/>
          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
        </body>
      </body>
    </body>
  </worldbody>

  <actuator>
    <position class="thigh" name="FL_thigh" joint="FL_thigh_joint" gear="1" kp="15" kv="1"/>
    <position class="calf" name="FL_calf" joint="FL_calf_joint" gear="1" kp="30" kv="1"/>
    <position class="thigh" name="FR_thigh" joint="FR_thigh_joint" gear="1" kp="15" kv="1"/>
    <position class="calf" name="FR_calf" joint="FR_calf_joint" gear="1" kp="30" kv="1"/>
    <position class="thigh" name="RL_thigh" joint="RL_thigh_joint" gear="1" kp="15" kv="1"/>
    <position class="calf" name="RL_calf" joint="RL_calf_joint" gear="1" kp="30" kv="1"/>
    <position class="thigh" name="RR_thigh" joint="RR_thigh_joint" gear="1" kp="15" kv="1"/>
    <position class="calf" name="RR_calf" joint="RR_calf_joint" gear="1" kp="30" kv="1"/>
  </actuator>

  <sensor>
    <gyro site="imu" name="gyro"/>
    <velocimeter site="imu" name="local_linvel"/>
    <accelerometer site="imu" name="accelerometer"/>
    <framepos objtype="site" objname="imu" name="position"/>
    <framezaxis objtype="site" objname="imu" name="upvector"/>
    <framexaxis objtype="site" objname="imu" name="forwardvector"/>
    <framelinvel objtype="site" objname="imu" name="global_linvel"/>
    <frameangvel objtype="site" objname="imu" name="global_angvel"/>
    <framequat objtype="site" objname="imu" name="orientation"/>
    <framelinvel objtype="site" objname="FL" name="FL_global_linvel"/>
    <framelinvel objtype="site" objname="FR" name="FR_global_linvel"/>
    <framelinvel objtype="site" objname="RL" name="RL_global_linvel"/>
    <framelinvel objtype="site" objname="RR" name="RR_global_linvel"/>
    <framepos objtype="site" objname="FL" name="FL_pos" reftype="site" refname="imu"/>
    <framepos objtype="site" objname="FR" name="FR_pos" reftype="site" refname="imu"/>
    <framepos objtype="site" objname="RL" name="RL_pos" reftype="site" refname="imu"/>
    <framepos objtype="site" objname="RR" name="RR_pos" reftype="site" refname="imu"/>
  </sensor>
</mujoco>

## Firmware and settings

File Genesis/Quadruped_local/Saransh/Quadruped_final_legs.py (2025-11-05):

from __future__ import print_function
import time
import math
import odrive
from odrive.enums import *
import numpy as np
from dataclasses import dataclass
from typing import Tuple, Optional
import threading
import Quadruped_leg_test_algo as qlt

@dataclass
class LegConfig:
    """Configuration parameters for a leg"""
    L1: float = 25.0  # Upper leg length (hip to knee)
    L2: float = 33.0  # Lower leg length (knee to foot)
    hip_pole_pairs: int = 20
    knee_pole_pairs: int = 7
    hip_encoder_cpr: int = 2400
    knee_encoder_cpr: int = 42
    is_mirrored: bool = False  # True for right legs, False for left legs

class Motor:
    """Class to handle ODrive motor configuration and control"""
    def __init__(self, axis, config: dict):
        self.axis = axis
        self.configure(config)
        
    def configure(self, config: dict):
        """Configure motor parameters"""
        # for param, value in config.items():
        #     setattr(self.axis, param, value)
        for param, value in config.items():
            attrs = param.split('.')
            obj = self.axis
            for attr in attrs[:-1]:
                obj = getattr(obj, attr)
            setattr(obj, attrs[-1], value)
    
    def calibrate(self):
        """Perform motor calibration sequence"""
        # Motor calibration
        self.axis.requested_state = AxisState.MOTOR_CALIBRATION
        time.sleep(7.5)
        self.axis.motor.config.pre_calibrated = True
        
        # Encoder calibration
        self.axis.encoder.config.calib_range = 0.1
        self.axis.requested_state = AxisState.ENCODER_OFFSET_CALIBRATION
        time.sleep(17)
        self.axis.encoder.config.pre_calibrated = True
        
    def set_closed_loop_control(self):
        """Set motor to closed loop control mode"""
        self.axis.requested_state = AxisState.CLOSED_LOOP_CONTROL
        
    def set_position(self, position: float):
        """Set motor position"""
        self.axis.controller.input_pos = float(position)

class Leg:
    """Class to handle a single leg of the quadruped"""
    def __init__(self, odrv, config: LegConfig):
        self.odrv = odrv
        self.config = config
        self.hip_motor = None
        self.knee_motor = None
        self.zero_hip = 0
        self.zero_knee = 0
        
    def setup_motors(self, hip_axis, knee_axis):
        """Initialize and configure motors"""
        # Hip motor configuration
        hip_config = {
            'motor.config.pole_pairs': self.config.hip_pole_pairs,
            'motor.config.motor_type': MotorType.HIGH_CURRENT,
            'motor.config.resistance_calib_max_voltage': 12,
            'motor.config.calibration_current': 18,
            'motor.config.current_lim': 20.0,
            'motor.config.requested_current_range': 25.0,
            'config.calibration_lockin.current': 20,
            'encoder.config.bandwidth': 750,
            'encoder.config.mode': EncoderMode.INCREMENTAL,
            'encoder.config.cpr': self.config.hip_encoder_cpr,
            'controller.config.control_mode': ControlMode.POSITION_CONTROL,
            'controller.config.pos_gain': 50.0,
            'controller.config.vel_gain': 0.05,
            'controller.config.vel_integrator_gain': 0.0,
            'trap_traj.config.vel_limit': 10,
            'trap_traj.config.accel_limit': 5,
            'trap_traj.config.decel_limit': 5,
            'controller.config.vel_limit': 15.0,
            'controller.config.input_mode': InputMode.TRAP_TRAJ
        }
        
        # Knee motor configuration
        knee_config = {
            'motor.config.pole_pairs': self.config.knee_pole_pairs,
            'motor.config.motor_type': MotorType.HIGH_CURRENT,
            'motor.config.resistance_calib_max_voltage': 12,
            'motor.config.calibration_current': 22,
            'motor.config.current_lim': 60.0,
            'motor.config.requested_current_range': 70.0,
            'config.calibration_lockin.current': 33,
            'encoder.config.bandwidth': 100,
            'encoder.config.mode': EncoderMode.HALL,
            'encoder.config.cpr': self.config.knee_encoder_cpr,
            'controller.config.control_mode': ControlMode.POSITION_CONTROL,
            'controller.config.pos_gain': 20,
            'controller.config.vel_gain': 0.02,
            'controller.config.vel_integrator_gain': 0.1,
            'trap_traj.config.vel_limit': 20,
            'trap_traj.config.accel_limit': 10,
            'trap_traj.config.decel_limit': 10,
            'controller.config.vel_limit': 20.0,
            'controller.config.input_mode': InputMode.TRAP_TRAJ
        }
        
        self.hip_motor = Motor(hip_axis, hip_config)
        self.knee_motor = Motor(knee_axis, knee_config)
    
    def calibrate(self):
        """Calibrate both motors"""
        print("Calibrating hip motor...")
        self.hip_motor.calibrate()
        print("Calibrating knee motor...")
        self.knee_motor.calibrate()
        
        self.hip_motor.set_closed_loop_control()
        self.knee_motor.set_closed_loop_control()
    
    def set_zero_position(self):
        """Set current position as zero reference"""
        self.Calib_pos_hip = 0
        self.Calib_pos_knee = 0

        while self.Calib_pos_hip != 69.0:
            self.hip_motor.set_position(self.Calib_pos_hip)
            self.knee_motor.set_position(self.Calib_pos_knee)

            self.Calib_pos_hip = float(input("Enter Calib_pos_hip Pweaseee... : "))
            self.Calib_pos_knee = float(input("Enter Calib_Calib_pos_knee Pweaseee... : "))

        self.zero_hip = self.hip_motor.axis.encoder.pos_estimate
        self.zero_knee = self.knee_motor.axis.encoder.pos_estimate
        
    def move_to_angles(self, hip_angle: float, knee_angle: float):
        """Move leg to specified joint angles"""
        # Apply mirroring if needed
        if self.config.is_mirrored:
            hip_angle = -hip_angle
            
        self.hip_motor.set_position(self.zero_hip + hip_angle)
        self.knee_motor.set_position(self.zero_knee + knee_angle)
        
    def move_to_point(self, x: float, height: float) -> bool:
        """Move end effector to specified point using inverse kinematics"""
        try:
            alpha, beta = qlt.solve_M(
                self.config.L1, 
                self.config.L2,
                x,
                height
            )
            
            # Convert to motor angles
            hip_angle = (((1.57 - alpha) * 1) / 6.28) * 10.5
            knee_angle = ((1.57 - alpha + beta - 1.12) * 4.58)
            
            self.move_to_angles(hip_angle, knee_angle)
            return True
        except ValueError as e:
            print(f"Invalid position: {e}")
            return False

class Quadruped:
    """Class to manage all four legs of the quadruped"""
    def __init__(self):
        self.odrives = []
        self.legs = {}
        self.leg_configs = {
            'front_left': LegConfig(is_mirrored=False),
            'front_right': LegConfig(is_mirrored=True),
            'back_left': LegConfig(is_mirrored=False),
            'back_right': LegConfig(is_mirrored=True)
        }
        
    def connect(self):
        """Connect to ODrives by serial and initialize"""
        print("Connecting to ODrives by serial...")
        serial_leg_map = {
            '3670314C3333': 'front_left',
            '366B315F3333': 'front_right',
            '3669315C3333': 'back_left',
            '367031553333': 'back_right'
        }
        self.odrives = []
        self.odrive_leg_map = {}
        for serial, leg_name in serial_leg_map.items():
            print(f"Connecting to ODrive for {leg_name} (serial: {serial})...")
            odrv = odrive.find_any(serial_number=serial)
            print(f"Connected to ODrive for {leg_name}: {odrv.serial_number}")
            self.odrives.append(odrv)
            self.odrive_leg_map[leg_name] = odrv
            # Configure each ODrive
            odrv.config.brake_resistance = 0.5
            odrv.config.dc_max_positive_current = 70
            odrv.config.dc_max_negative_current = -2.0
            odrv.config.max_regen_current = 0
        
    def setup_leg(self, name: str, odrv, hip_axis, knee_axis, config: LegConfig):
        """Setup a single leg"""
        leg = Leg(odrv, config)
        leg.setup_motors(hip_axis, knee_axis)
        self.legs[name] = leg
        
    def setup_all_legs(self):
        """Setup all four legs with appropriate configurations using explicit serial mapping"""
        for leg_name, odrv in self.odrive_leg_map.items():
            config = self.leg_configs[leg_name]
            self.setup_leg(leg_name, odrv, odrv.axis0, odrv.axis1, config)
            # if leg_name == 'front_right':
            #     odrv.axis1.encoder.config.cpr = 28  # Specific adjustment for front right knee
            print(f"Set up {leg_name} leg with ODrive serial {odrv.serial_number}")
        
    def calibrate_leg_thread(self, name, leg):
        print(f"Calibrating {name}...")
        leg.calibrate()

    def calibrate_all_legs(self, simultaneous=True):
        """Calibrate all legs, either simultaneously (default) or sequentially."""
        if simultaneous:
            threads = []
            for name, leg in self.legs.items():
                t = threading.Thread(target=self.calibrate_leg_thread, args=(name, leg))
                t.start()
                threads.append(t)
            for t in threads:
                t.join()
        else:
            for name, leg in self.legs.items():
                self.calibrate_leg_thread(name, leg)
            
    def set_all_zero_positions(self):
        """Set zero positions for all legs"""
        for leg in self.legs.values():
            leg.set_zero_position()

def main():
    # Create quadruped instance
    quad = Quadruped()
    
    try:
        # Connect to all ODrives
        quad.connect()

        # Setup all legs
        quad.setup_all_legs()

        # Ask user if they want simultaneous or sequential calibration
        print("\nCalibration mode:")
        print("1. Simultaneous (default)")
        print("2. Sequential")
        mode = input("Select calibration mode (1/2, default 1): ").strip()
        simultaneous = (mode != "2")
        # Calibrate all legs
        print("\nStarting calibration of all legs...")
        quad.calibrate_all_legs(simultaneous=simultaneous)

        print("\nSetting zero positions for all legs...")
        quad.set_all_zero_positions()

        # Test movement of each leg
        while True:
            try:
                # Select leg to move
                print("\nAvailable legs:")
                print("1. Front Left")
                print("2. Front Right")
                print("3. Back Left")
                print("4. Back Right")
                print("0. Exit")

                choice = int(input("\nSelect leg to move (0-4): "))
                if choice == 0:
                    break

                leg_map = {
                    1: 'front_left',
                    2: 'front_right',
                    3: 'back_left',
                    4: 'back_right'
                }

                if choice not in leg_map:
                    print("Invalid choice!")
                    continue

                leg = quad.legs[leg_map[choice]]

                # Get movement coordinates
                x = float(input("Enter x position (-20 to 20): "))
                height = float(input("Enter height (0 to 40): "))

                # Move leg
                leg.move_to_point(x, height)

            except ValueError as e:
                print(f"Invalid input: {e}")
            except KeyboardInterrupt:
                break

    except KeyboardInterrupt:
        print("\nExiting...")
    finally:
        # Set all motors to idle state
        print("\nSetting all motors to idle state...")
        for odrv in quad.odrives:
            odrv.axis0.requested_state = AxisState.IDLE
            odrv.axis1.requested_state = AxisState.IDLE

if __name__ == "__main__":
    main()

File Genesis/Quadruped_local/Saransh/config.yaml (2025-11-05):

# Quadruped Configuration File
# This file contains all ODrive and system parameters that can be easily modified

# System Settings
system:
  simulation_mode: false  # Set to true to run without ODrive connection
  default_calibration_mode: "simultaneous"  # "simultaneous" or "sequential"
  
# ODrive Serial to Leg Mapping
odrive_mapping:
  "3670314C3333": "front_left"
  "366B315F3333": "front_right" 
  "3669315C3333": "back_left"                      
  "367031553333": "back_right"

# Leg Configuration
leg_config:
  L1: 25.0  # Upper leg length (hip to knee) in cm
  L2: 33.0  # Lower leg length (knee to foot) in cm
  
  # Encoder settings
  hip_pole_pairs: 20
  knee_pole_pairs: 7
  hip_encoder_cpr: 2400
  knee_encoder_cpr: 42

# ODrive Hardware Configuration
odrive_config:
  brake_resistance: 0.5
  dc_max_positive_current: 70
  dc_max_negative_current: -2.0
  max_regen_current: 0

# Motor Configurations
motor_config:
  hip:
    motor_type: "HIGH_CURRENT"
    resistance_calib_max_voltage: 10
    calibration_current: 18
    current_lim: 20.0
    requested_current_range: 22.0
    calibration_lockin_current: 20
    encoder_bandwidth: 750
    encoder_mode: "INCREMENTAL"
    
    # Control parameters
    control_mode: "POSITION_CONTROL"
    input_mode: "TRAP_TRAJ"
    pos_gain: 50.0
    vel_gain: 0.05
    vel_integrator_gain: 0.0
    vel_limit: 10.0
    
    # Trajectory parameters
    trap_traj_vel_limit: 10
    trap_traj_accel_limit: 15
    trap_traj_decel_limit: 15

  knee:
    motor_type: "HIGH_CURRENT"
    resistance_calib_max_voltage: 12
    calibration_current: 22
    current_lim: 60.0
    requested_current_range: 70.0
    calibration_lockin_current: 33
    encoder_bandwidth: 100
    encoder_mode: "HALL"
    current_control_bandwidth: 1500  # Increase current loop bandwidth
    
    # Control parameters
    control_mode: "POSITION_CONTROL"
    input_mode: "TRAP_TRAJ"
    pos_gain: 50
    vel_gain: 0.02 # Increased from 0.0125 for better tracking
    vel_integrator_gain: 0.0  # Added some integral gain to reduce steady-state error
    vel_limit: 50.0
    vel_limit_tolerance: 1.2  # Allow some velocity overshoot
    enable_vel_limit: true
    torque_ramp_rate: 0.01  # Limit torque change rate
    
    # Trajectory parameters - made less aggressive
    trap_traj_vel_limit: 50  # Reduced from 30
    trap_traj_accel_limit: 100  # Reduced from 50
    trap_traj_decel_limit: 100  # Reduced from 50

# Leg-specific overrides (optional)
leg_specific:
  front_right:
    is_mirrored: true
    # knee_encoder_cpr: 28  # Uncomment if needed
  front_left:
    is_mirrored: false
  back_left:
    is_mirrored: false
  back_right:
    is_mirrored: true
    # knee_encoder_cpr: 28  # Uncomment if needed

# GUI Settings
gui:
  window_title: "Quadruped Control Interface"
  window_size: [1600, 1000]  # Increased for single screen layout
  update_rate_ms: 50  # GUI update rate in milliseconds
  plot_history_length: 1000  # Number of data points to keep in plots
  
  # Theme configuration (ERC colors - dark theme)
  theme:
    background: "#1e1e1e"      # Dark grey background
    surface: "#2d2d2d"         # Slightly lighter grey for panels
    primary: "#0078d4"         # Blue (ERC blue)
    secondary: "#ffffff"       # White text
    accent: "#005a9e"          # Darker blue for accents
    text_primary: "#ffffff"    # White text
    text_secondary: "#cccccc"  # Light grey text
    success: "#107c10"         # Green for success
    warning: "#ff8c00"         # Orange for warnings
    error: "#d13438"           # Red for errors

# Visualization Settings
visualization:
  body_length: 42.0  # Distance between front and back legs
  body_width: 35.8   # Distance between left and right legs
  default_joint_angles:
    hip: 0.0
    knee: 0.0
  animation_speed: 1.0
  show_coordinate_frame: true

# Joint Angle Limits (in degrees)
joint_limits:
  # Animation/visualization limits (for sliders and display)
  animation:
    hip:
      min: -120
      max: 120
    knee:
      min: -140
      max: 140
  
  # Hardware safety limits (actual commands sent to motors)
  hardware:
    hip:
      min: -90
      max: 90
    knee:
      min: -120
      max: 120
  
# Safety Limits
safety:
  max_current: 80.0
  max_velocity: 25.0
  max_position_error: 5.0
  emergency_stop_enabled: true

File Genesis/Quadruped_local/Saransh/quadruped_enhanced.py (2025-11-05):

#!/usr/bin/env python3
"""
Enhanced Quadruped Control System with Config File Support
This is an enhanced version of Quadruped_final_legs.py that works with the new GUI system
"""

from __future__ import print_function
import time
import math
import yaml
import numpy as np
from dataclasses import dataclass
from typing import Tuple, Optional
import threading

try:
    import odrive
    from odrive.enums import *
    ODRIVE_AVAILABLE = True
except ImportError:
    print("ODrive not available - simulation mode only")
    ODRIVE_AVAILABLE = False
    # Create dummy classes for simulation
    class AxisState:
        IDLE = 1
        MOTOR_CALIBRATION = 3
        ENCODER_OFFSET_CALIBRATION = 6
        CLOSED_LOOP_CONTROL = 8
    
    class MotorType:
        HIGH_CURRENT = 0
    
    class EncoderMode:
        INCREMENTAL = 0
        HALL = 1
    
    class ControlMode:
        POSITION_CONTROL = 3
    
    class InputMode:
        TRAP_TRAJ = 5

try:
    import Quadruped_leg_test_algo as qlt
except ImportError:
    print("Warning: Quadruped_leg_test_algo not found")
    # Create dummy functions
    class qlt:
        @staticmethod
        def solve_M(L1, L2, x, height):
            # Simple inverse kinematics approximation
            distance = np.sqrt(x**2 + height**2)
            if distance > L1 + L2:
                raise ValueError("Position unreachable")
            
            alpha = np.arccos((L1**2 + distance**2 - L2**2) / (2 * L1 * distance))
            beta = np.arccos((L1**2 + L2**2 - distance**2) / (2 * L1 * L2))
            
            return alpha, beta


@dataclass
class LegConfig:
    """Configuration parameters for a leg"""
    L1: float = 25.0  # Upper leg length (hip to knee)
    L2: float = 33.0  # Lower leg length (knee to foot)
    hip_pole_pairs: int = 20
    knee_pole_pairs: int = 7
    hip_encoder_cpr: int = 2400
    knee_encoder_cpr: int = 42
    is_mirrored: bool = False  # True for right legs, False for left legs

    @classmethod
    def from_config(cls, config_dict, leg_specific_config=None):
        """Create LegConfig from configuration dictionary"""
        leg_config = config_dict.get('leg_config', {})
        
        # Start with base config
        kwargs = {
            'L1': leg_config.get('L1', 25.0),
            'L2': leg_config.get('L2', 33.0),
            'hip_pole_pairs': leg_config.get('hip_pole_pairs', 20),
            'knee_pole_pairs': leg_config.get('knee_pole_pairs', 7),
            'hip_encoder_cpr': leg_config.get('hip_encoder_cpr', 2400),
            'knee_encoder_cpr': leg_config.get('knee_encoder_cpr', 42),
            'is_mirrored': False
        }
        
        # Apply leg-specific overrides
        if leg_specific_config:
            kwargs.update(leg_specific_config)
        
        return cls(**kwargs)


class Motor:
    """Class to handle ODrive motor configuration and control"""
    def __init__(self, axis, config: dict, simulation_mode=False):
        self.axis = axis
        self.simulation_mode = simulation_mode
        if not simulation_mode:
            self.configure(config)
        
    def configure(self, config: dict):
        """Configure motor parameters"""
        if self.simulation_mode:
            return
            
        print(f"Configuring motor with parameters: {config}")
            
        # Convert string motor types and modes to enums
        enum_mappings = {
            'HIGH_CURRENT': MotorType.HIGH_CURRENT,
            'INCREMENTAL': EncoderMode.INCREMENTAL,
            'HALL': EncoderMode.HALL,
            'POSITION_CONTROL': ControlMode.POSITION_CONTROL,
            'TRAP_TRAJ': InputMode.TRAP_TRAJ
        }
        
        for param, value in config.items():
            # Convert enum strings to actual enums
            if isinstance(value, str) and value in enum_mappings:
                value = enum_mappings[value]
                
            print(f"Setting {param} = {value}")
            
            try:
                # Navigate nested attributes
                attrs = param.split('.')
                obj = self.axis
                for attr in attrs[:-1]:
                    obj = getattr(obj, attr)
                setattr(obj, attrs[-1], value)
                
                # Verify the setting was applied (for important parameters)
                if any(key in param for key in ['current_lim', 'calibration_current', 'calibration_lockin']):
                    final_obj = self.axis
                    for attr in attrs[:-1]:
                        final_obj = getattr(final_obj, attr)
                    actual_value = getattr(final_obj, attrs[-1])
                    print(f"✓ Verification: {param} = {actual_value}")
                    
            except Exception as e:
                print(f"✗ Error setting {param}: {e}")
        
        print("Motor configuration completed")
    
    def calibrate(self):
        """Perform motor calibration sequence"""
        if self.simulation_mode:
            print("Simulation: Motor calibration")
            time.sleep(0.1)  # Quick simulation
            return
            
        # Motor calibration
        self.axis.requested_state = AxisState.MOTOR_CALIBRATION
        time.sleep(7.5)
        self.axis.motor.config.pre_calibrated = True
        
        # Encoder calibration
        self.axis.encoder.config.calib_range = 0.1
        self.axis.requested_state = AxisState.ENCODER_OFFSET_CALIBRATION
        time.sleep(17)
        self.axis.encoder.config.pre_calibrated = True
        
    def set_closed_loop_control(self):
        """Set motor to closed loop control mode"""
        if not self.simulation_mode:
            self.axis.requested_state = AxisState.CLOSED_LOOP_CONTROL
        
    def set_position(self, position: float):
        """Set motor position"""
        if not self.simulation_mode:
            self.axis.controller.input_pos = float(position)
    
    def get_current(self):
        """Get motor current"""
        if self.simulation_mode:
            return 2.0 + 0.5 * np.random.randn()
        try:
            return self.axis.motor.current_control.Iq_measured
        except:
            return 0.0
    
    def get_position(self):
        """Get motor position"""
        if self.simulation_mode:
            return 10.0 * np.random.randn()
        try:
            return self.axis.encoder.pos_estimate
        except:
            return 0.0
    
    def get_velocity(self):
        """Get motor velocity"""
        if self.simulation_mode:
            return 5.0 * np.random.randn()
        try:
            return self.axis.encoder.vel_estimate
        except:
            return 0.0
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

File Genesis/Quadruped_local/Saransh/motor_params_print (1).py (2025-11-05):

from __future__ import print_function
import odrive
import time

# Connect to ODrive
print("Connecting to ODrive...")
odrv0 = odrive.find_any()
print("Connected!")

# Print general settings
print("\n--- General ODrive Settings ---")
print(f"DC Max Positive Current: {odrv0.config.dc_max_positive_current} A")
print(f"DC Max Negative Current: {odrv0.config.dc_max_negative_current} A")
print(f"DC Bus Voltage: {odrv0.vbus_voltage} V")

# Select the axis (change to axis0 if needed)
axis = odrv0.axis1  

# Print Motor Config
print("\n--- Motor Configuration ---")
print(f"Motor Type: {axis.motor.config.motor_type}")
print(f"Current Limit: {axis.motor.config.current_lim} A")
print(f"Requested Current Range: {axis.motor.config.requested_current_range} A")
print(f"Phase Resistance: {axis.motor.config.phase_resistance} Ω")
print(f"Phase Inductance: {axis.motor.config.phase_inductance} H")
print(f"Current Control Bandwidth: {axis.motor.config.current_control_bandwidth} Hz")
print(f"Calibration Current: {axis.motor.config.calibration_current} A")

# Print Encoder Config
print("\n--- Encoder Configuration ---")
print(f"Encoder Mode: {axis.encoder.config.mode}")
print(f"Encoder CPR: {axis.encoder.config.cpr}")
print(f"Encoder Bandwidth: {axis.encoder.config.bandwidth}")
print(f"Encoder Calibration Range: {axis.encoder.config.calib_range}")

# Print Controller Config
print("\n--- Controller Configuration ---")
print(f"Control Mode: {axis.controller.config.control_mode}")
print(f"Input Mode: {axis.controller.config.input_mode}")
print(f"Position Gain: {axis.controller.config.pos_gain}")
print(f"Velocity Gain: {axis.controller.config.vel_gain}")
print(f"Velocity Integral Gain: {axis.controller.config.vel_integrator_gain}")
print(f"Torque Gain: {axis.controller.config.torque_gain}")

# Print Thermal Status
print("\n--- Thermal Monitoring ---")
print(f"FET Thermistor Temperature: {axis.motor.fet_thermistor.temperature} °C")
print(f"Motor Thermistor Temperature: {axis.motor.motor_thermistor.temperature} °C")

# Print Live Current Limits
print("\n--- Live Current Monitoring ---")
print(f"Iq Setpoint: {axis.motor.current_control.Iq_setpoint} A")
print(f"Iq Measured: {axis.motor.current_control.Iq_measured} A")
print(f"Bus Current: {odrv0.ibus_}{axis.motor.current_control.final_v_alpha}")

print("\nDone checking parameters!")

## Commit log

2025-11-04 Added Genesis files
    [FL_calf.STL, FL_thigh.STL, FR_calf.STL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]
2025-11-05 fixed training script
    [Assem1.urdf, FL_calf.STL, FL_thigh.STL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]
2026-06-30 gearbox section updated in docs
2026-07-31 leg design section update

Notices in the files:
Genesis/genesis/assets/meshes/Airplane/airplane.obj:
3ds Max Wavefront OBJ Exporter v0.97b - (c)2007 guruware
